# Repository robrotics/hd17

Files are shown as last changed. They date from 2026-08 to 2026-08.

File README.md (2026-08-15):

# HD20: a 3D-printable 20:1 harmonic drive actuator

A strain-wave (harmonic) gearbox that bolts onto a standard NEMA 17 stepper,
prints on a bog-standard bed slinger, and costs about **$4 of hardware** per
unit. Tested to **3.3 N·m**.

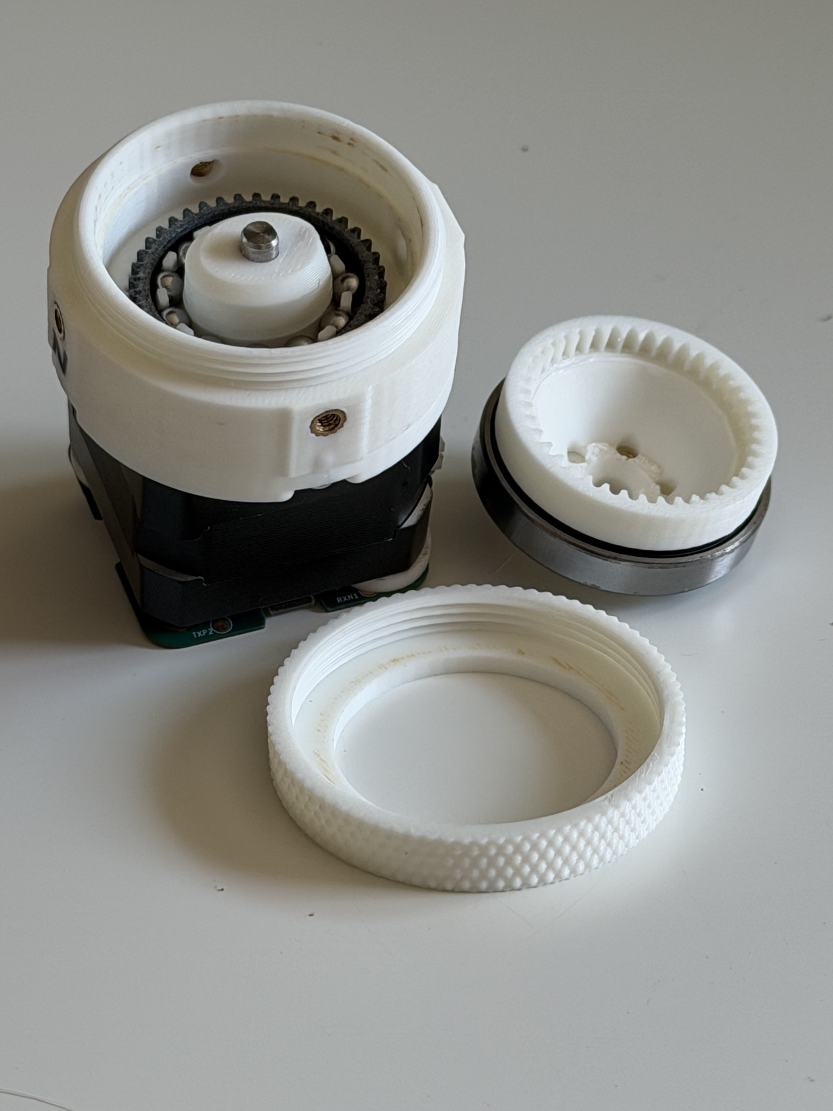
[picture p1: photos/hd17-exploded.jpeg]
HD20, exploded


| | |
|---|---|
| **Reduction** | 20:1 |
| **Tooth profile** | Cycloidal, module 0.8 |
| **Measured torque** | 2.1–2.6 N·m @ 0.7 A · 3.0–3.3 N·m @ 1.4 A (peak 3.5 N·m) |
| **Efficiency** | 48–58% |
| **Backlash** | measurement in progress |
| **Motor** | Any NEMA 17 with a 5 mm shaft (tested: [OMC 17HE12-1204S](https://www.omc-stepperonline.com/e-series-nema-17-bipolar-26ncm-36-82oz-in-1-2a-42x42x30mm-4-wires-w-1m-cable-connector-17he12-1204s), 26 N·cm, 1.2 A) |
| **Lubrication** | Super Lube synthetic PTFE grease |
| **Printed parts** | 10 pieces across 9 unique parts, including 2 shear pins |
| **Fasteners** | 8 × M3×0.5 × 6 mm button head screws per drive |
| **Hardware cost** | ~$3.96 per actuator |
| **Version** | v1.0 (RevA, 2026-08-09) |
| **License** | [CC BY-SA 4.0](LICENSE) |

> **Testing is ongoing.** The numbers above come from the load-cell runs in
> [`docs/torque-test-report.html`](docs/torque-test-report.html). We're in the
> middle of revising the test method, so expect these figures to be updated.
> Read the honest caveats in [Known behaviour](#known-behaviour) before you
> build.

---

## How it works

Three parts do the work. A **wave generator**, an ellipse riding on 11 loose
5 mm balls in a printed cage, pushes a flexible toothed ring (the
**flexspline**) into an oval, so its teeth engage a rigid ring (the **circular
spline**) at just two points. The circular spline has two more teeth than the
flexspline, so one turn of the motor walks the output around by two teeth. That
tiny slip per revolution is the 20:1.

New to strain-wave gearing? We wrote a plain-language explainer:
**[robrotics.web.app/learn](https://robrotics.web.app/learn)**.

The tooth profile came out of our own free generator,
**[the harmonic maker](https://robrotics.web.app/gearmaker)**. You can use it
to make profiles for your own drives.

## What you need

**Not included in the BOM, bring your own:**

- A **NEMA 17 stepper with a 5 mm shaft**. We tested with an
  [OMC StepperOnline 17HE12-1204S](https://www.omc-stepperonline.com/e-series-nema-17-bipolar-26ncm-36-82oz-in-1-2a-42x42x30mm-4-wires-w-1m-cable-connector-17he12-1204s)
  (42 × 42 × 30 mm, 26 N·cm, 1.2 A, 4-wire) under closed-loop FOC control; an
  open-loop stepper on a basic driver will behave differently.
- **4 × M3 screws** to bolt the motor to the interface plate. These are
  separate from the 8 × M3×0.5 × 6 mm screws that hold the drive together,
  which are in the BOM.
- A **soldering iron** for the heat-set inserts, and hex keys.

**Filament:** PLA for everything except the flexspline, which must be **PETG**.

> ⚠️ **Do not print the flexspline in PLA.** It flexes on every single
> revolution. PLA has almost no fatigue life in that duty and will crack.

## Bill of materials

Machine-readable source: [`bom.json`](bom.json).

| # | Item | Qty | Pack | Pack cost | Per actuator |
|---|---|-----|---|---|---|
| 1 | M3 heat-set inserts | 12 | 100 | $9.99 | $1.20 |
| 2 | M3×0.5 × 6 mm button head, stainless | 8 | 100 | $7.69 | $0.62 |
| 3 | 30 × 42 × 7 mm bearing | 1 | 10 | $16.39 | $1.64 |
| 4 | Set screw | 1 | 50 | $5.69 | $0.11 |
| 5 | 5 mm steel bearing balls | 11 | 200 | $7.20 | $0.40 |
| 6 | Super Lube synthetic grease | 1 | — | — | — |
| | | | | **$46.96 buy-in** | **$3.96 each** |

One tube of grease lasts many builds, so it isn't counted in the per-unit cost.

Parts are sold in packs, so the first actuator costs about $47 in hardware and
every one after that costs about $4, and you'll have enough left over for
eight more.

> **Affiliate disclosure:** the purchase links in `bom.json` and on our website
> are Amazon Associates links. If you buy through one, Robrotics earns a small
> commission at no extra cost to you. Every part listed is what we actually
> used; the links don't change the recommendation.

## Printed parts

| Part | Qty | Material | File |
|---|---|---|---|
| Circular spline (base) | 1 | PLA | `hd17-circular-spline-base` |
| Circular spline (output) | 1 | PLA | `hd17-circular-spline-output` |
| Base preloader | 1 | PLA | `hd17-base-preloader` |
| Output preloader | 1 | PLA | `hd17-output-preloader` |
| Interface / motor mount | 1 | PLA | `hd17-interface` |
| Wave generator | 1 | PLA | `hd17-wave-generator` |
| Ball cage | 1 | PLA | `hd17-cage` |
| **Flexspline** | 1 | **PETG** | `hd17-flexspline-petg` |
| Shear pin | **2** | PLA | `hd17-shear-pin` |

**Both shear pins are required.** They carry shear load across the output joint
directly, so the connection doesn't have to rely on friction from the preloaded
screws to resist it. The screws clamp; the pins take the sideways load.

### Print settings

The tested units were printed on a **Bambu Lab P1S** with **Bambu PLA** (and
PETG for the flexspline), using:

- **Arachne** variable-width wall generator
- **One extra wall loop** for strength
- **Seam position: random**, on every part, so a single seam line doesn't stack
  up into a weak spot or a visible ridge on the round surfaces
- **Supports on the output circular spline and the interface.** Everything else
  prints unsupported.

No custom temperatures, no special bed prep.

## Files

```
cad/step/          STEP, for CAD work and remixing
docs/              Load-cell torque test report
photos/            Build photos
bom.json           Bill of materials (source of truth)
```

Grab the packaged bundles from the
[Releases page](https://github.com/robrotics/hd17/releases) rather than
cloning, because the STEP files are large.

## Assembly

📹 **An assembly video is on the way** and it'll be posted to
[youtube.com/@robrotics](https://www.youtube.com/@robrotics) and linked here.

Written step-by-step instructions are being written up alongside it.

## Make your own version

The full parametric model is public on Onshape:

**[Open the HD20 in Onshape →](https://cad.onshape.com/documents/77afb05fe79876b7e72eef9d/w/f63b8b9736de29d04fb7333a/e/ae0695e56e320ee36980ab83)**

Copy it to your own workspace and change what you like: a different motor
face, a different output interface, a different ratio. If you build a variant,
we'd genuinely like to see it: open an issue or tag
[@robrotics](https://www.instagram.com/robrotics).

## Known behaviour

Read this before you conclude you assembled it wrong.

- **Torque drops about 10% after running in.** A freshly printed unit measured
  2.32 N·m; the same unit after further running measured 2.08 N·m at 0.7 A.
  This is expected, so plan around the run-in figure, not the fresh one.
- **Output spline preload changes everything.** Further tightening the output
  spline took one unit from 2.37 to 2.55 N·m. It's the single biggest tuning
  knob you have.
- **Unit-to-unit variation is real.** Two units of the same design differed by
  up to 18% at the same current. Printed gearboxes are not precision parts.
- **Efficiency is 48–58%**, so roughly half your motor torque becomes heat.
  Size the motor accordingly.
- **PLA creeps under sustained load.** Holding a heavy static load for hours
  will slowly deform the circular splines.
- **The 1.4 A figures are above the test motor's rating.** The 17HE12-1204S is
  rated 1.2 A, so the 3.0–3.3 N·m numbers were measured over-driven. Treat them
  as a short-burst ceiling, not a continuous rating. At 1.4 A that motor gets
  hot.

Found something we haven't listed? Please
[open an issue](https://github.com/robrotics/hd17/issues) and include your
version, filament, and printer.

## Test data

[`docs/torque-test-report.html`](docs/torque-test-report.html) is a standalone
page with the full load-cell traces: 7 configurations, ~1500–3000 samples each,
100 mm lever arm, raw counts scaled to N·m, with a no-gearbox baseline for the
efficiency maths. Open it in a browser.

## License

[CC BY-SA 4.0](LICENSE). Use it, change it, sell it. Just credit Robrotics and
share your derivatives under the same license.

**No warranty.** Printed parts fail. Don't put this anywhere a failure could
hurt someone.

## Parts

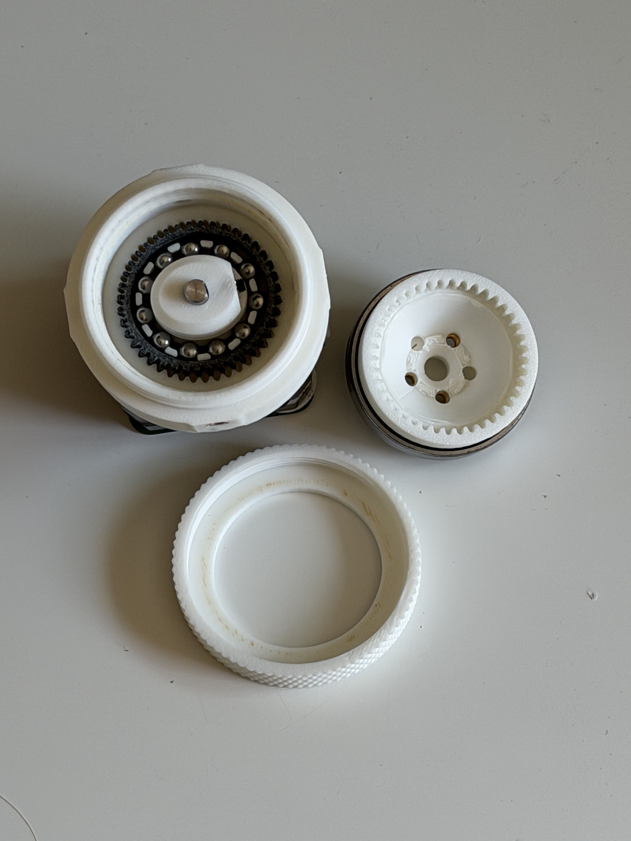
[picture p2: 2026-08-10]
photos/hd17-parts.jpeg

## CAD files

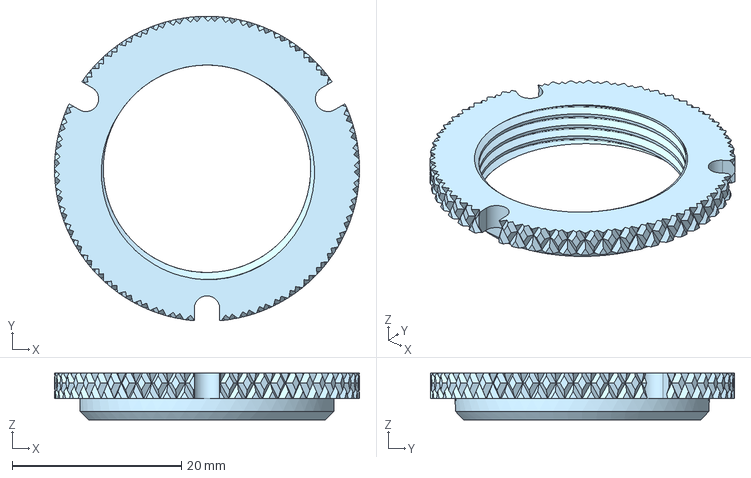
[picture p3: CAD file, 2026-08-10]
cad/step/hd17-base-preloader.step
36.0 x 35.9 x 5.50 mm

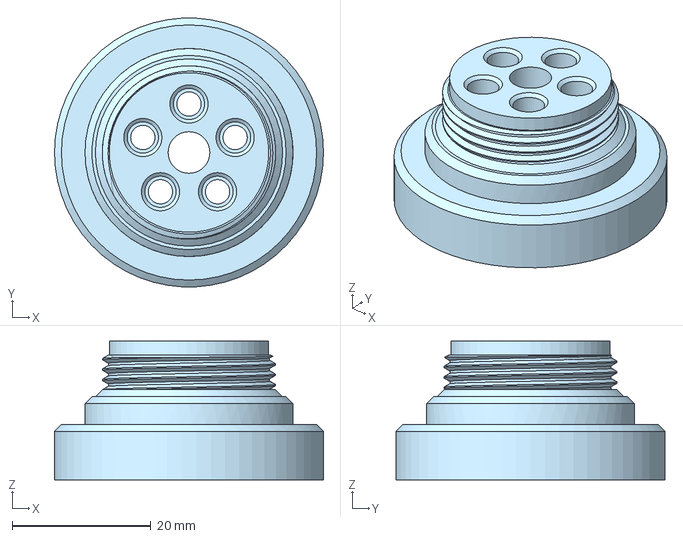
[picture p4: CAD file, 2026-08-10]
cad/step/hd17-circular-spline-output.step
38.8 x 38.7 x 20.0 mm

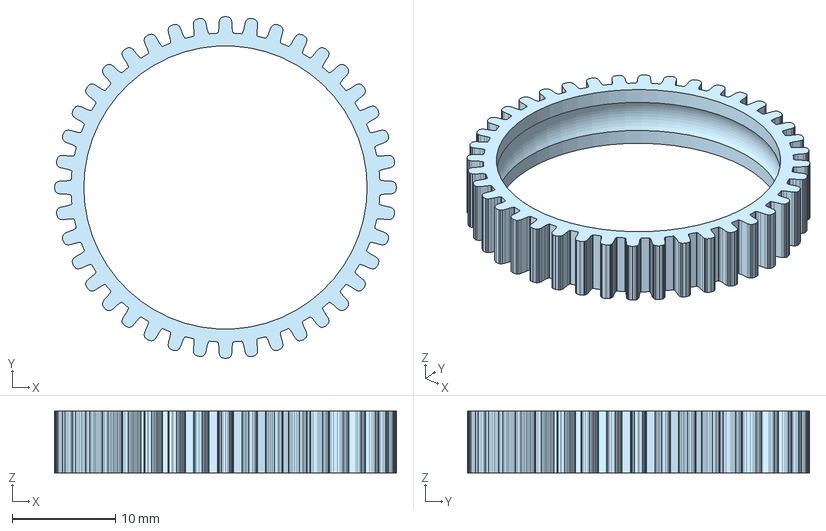
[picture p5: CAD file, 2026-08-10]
cad/step/hd17-flexspline-petg.step
33.2 x 33.2 x 6.00 mm

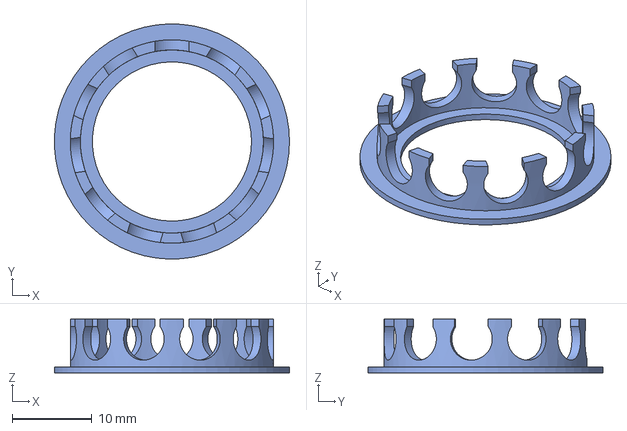
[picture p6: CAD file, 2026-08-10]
cad/step/hd17-cage.step
29.5 x 29.5 x 6.75 mm

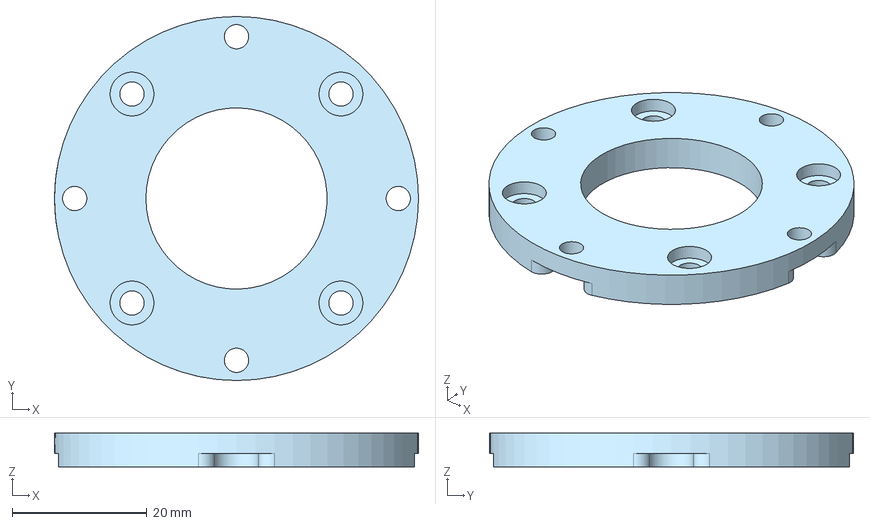
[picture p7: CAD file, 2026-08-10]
cad/step/hd17-interface.step
54.0 x 54.0 x 5.00 mm

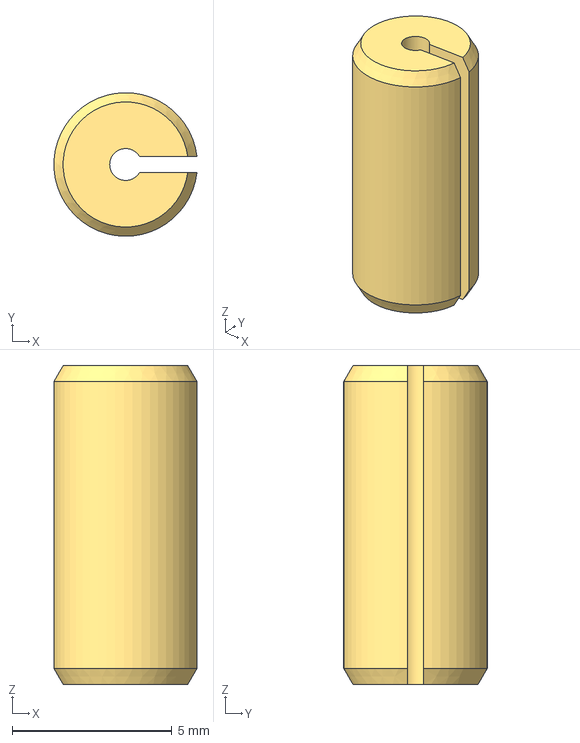
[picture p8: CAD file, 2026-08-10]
cad/step/hd17-shear-pin.step
4.48 x 4.50 x 10.0 mm

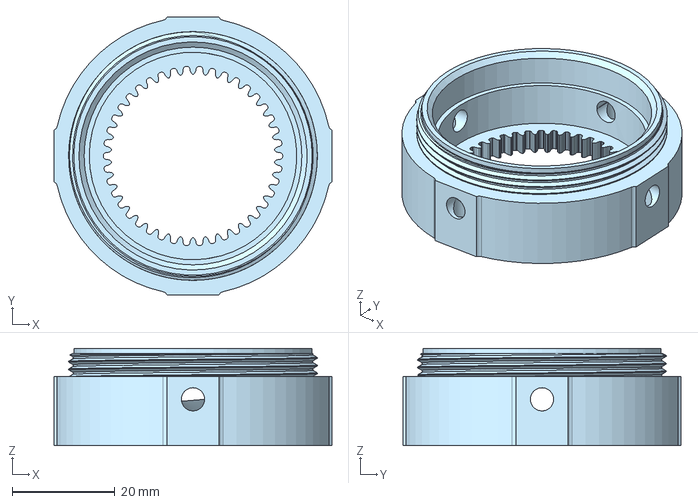
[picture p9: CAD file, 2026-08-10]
cad/step/hd17-circular-spline-base.step
54.0 x 54.0 x 18.9 mm

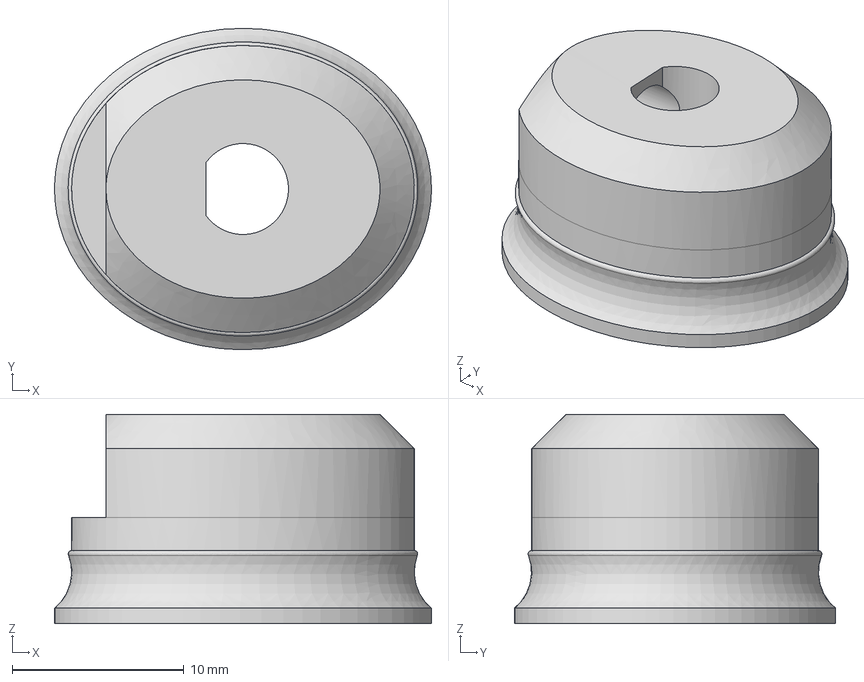
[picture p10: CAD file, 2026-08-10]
cad/step/hd17-wave-generator.step
22.0 x 18.7 x 12.2 mm

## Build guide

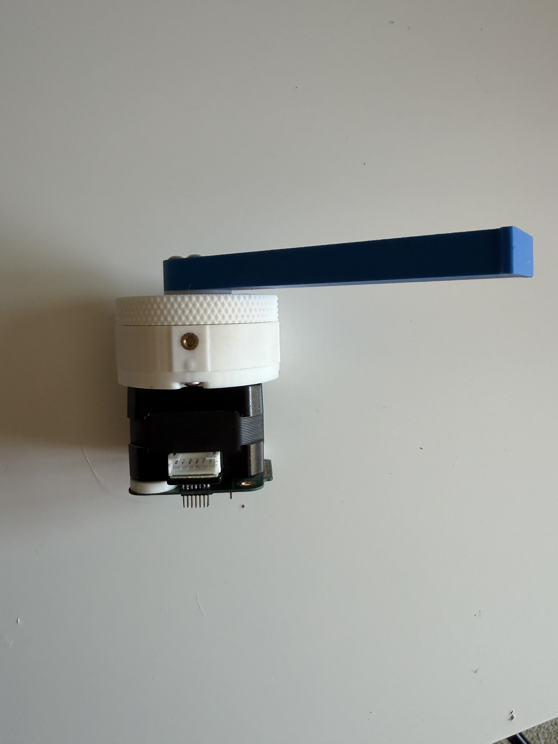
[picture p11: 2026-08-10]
photos/hd17-assembled.jpeg

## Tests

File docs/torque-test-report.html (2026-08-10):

# Cycloidal 20:1 — output spline torque test

Elliptical wave generator · PETG flex spline · FOC · 100 mm lever arm. Gearbox 1 is the 260704/260705 unit (tightened, then further super-tightened output spline). Gearbox 2 is a second printed unit (white filament) tested fresh off the printer, then again ("notfresh") after further running-in, at both 0.7 A and 1.4 A. The no-gearbox baseline is shared across all runs. Raw load-cell counts scaled ×980.7 to N·m (same factor as prior reports).

58%

best efficiency so far — gearbox 1, super-tightened, 0.7 A

53% → 48%

gearbox 2 efficiency, fresh → notfresh @ 0.7 A (-10.2% steady-state torque)

-18.4%

gearbox 2 (notfresh) vs gearbox 1 (super-tightened) @ 0.7 A

+9.3%

gearbox 2 (notfresh) vs gearbox 1 (tightened) @ 1.4 A

## Summary table

Configuration | Steady-state (N·m) | Peak (N·m) | 10–90% rise (s) | Duration (s) | Samples
No gearbox, 0.7 A | 0.219 ± 0.004 | 0.224 | 0.27 | 30.0 | 3000
Gearbox 1, tightened spline (260704), 0.7 A | 2.372 ± 0.046 | 2.595 | 0.03 | 17.9 | 1794
Gearbox 1, super-tightened spline (260705), 0.7 A | 2.552 ± 0.043 | 2.833 | 0.03 | 18.6 | 1860
Gearbox 2, fresh, 0.7 A | 2.320 ± 0.037 | 2.595 | 0.03 | 21.9 | 2186
Gearbox 2, notfresh, 0.7 A | 2.083 ± 0.037 | 2.282 | 0.03 | 29.1 | 2914
Gearbox 1, tightened spline (260704), 1.4 A | 3.009 ± 0.059 | 3.308 | 0.10 | 20.6 | 2059
Gearbox 2, notfresh, 1.4 A | 3.288 ± 0.062 | 3.528 | 0.08 | 14.9 | 1497

Steady-state = median of samples above 50% of peak; ± is one standard deviation over that plateau. Torque multiplication and efficiency are each computed against the shared no-gearbox 0.7 A baseline (ideal ratio 20:1).

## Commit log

2026-08-10 HD17 v1.0 (RevA) - printable 20:1 harmonic drive actuator
    3D-printable strain wave gearbox for a NEMA 17 stepper. 20:1 reduction,
    measured 2.1-3.3 N.m depending on drive current, ~$4 of hardware per unit.
    Includes STEP and 3MF for all nine printed parts, a matched MJF nylon set
    (flexspline, cage and wave generator - their geometry differs from the
    PETG versions and they must be used together), the bill of materials as
    machine-readable JSON, build photos, and the full load-cell torque test
    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
    [hd17-base-preloader.3mf, hd17-base-preloader.step, hd17-cage-mjf.3mf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]
2026-08-12 Rename the drive to HD20 and correct the build details
    The drive is now named after its 20:1 ratio rather than the NEMA 17 motor
    it bolts to. Repo and CAD filenames are still hd17 for now.
    Build corrections:
    - The shear pin is required, not optional, and there are 2 per drive.
    - Each drive takes 8 x M3x0.5 x 6 mm screws. With the 4 user-supplied
    motor screws that accounts for all 12 heat-set inserts, so the open
    question about the screw count is resolved and dropped.
    - The output circular spline and the interface need supports, and seam
    position is set to random on every part. The README previously said
    no supports were needed.
    - In the MJF matched set only the flexspline has to be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
2026-08-12 Remove the outdated 3MF files
    The exported 3MFs no longer match the current geometry, so they are
    removed rather than left to mislead builders. STEP and the live Onshape
    model are now the only sources; slice from STEP.
    [hd17-base-preloader.3mf, hd17-cage-mjf.3mf, hd17-cage.3mf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]
2026-08-15 Withdraw the nylon MJF flexspline variant
    The MJF version isn't performing well enough to recommend, so pull it
    until it does. Removes the matched three-part STEP set, the README
    section describing it, and the BOM note about printing the MJF cage and
    wave generator.
    The files remain in git history if the variant comes back.
    [hd17-cage-mjf.step, hd17-flexspline-mjf.step, hd17-wave-generator-mjf.step]
